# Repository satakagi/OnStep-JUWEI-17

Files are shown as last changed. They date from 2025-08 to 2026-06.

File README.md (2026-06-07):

# OnStep-JUWEI-17

## Table of Contents

- [Introduction](#introduction)  
- [Why This Project?](#why-this-project)  
- [Disclaimer](#disclaimer)  
- [Features](#features)  
- [Hardware](#hardware)  
- [Firmware and Config.h Configuration](#firmware-and-configh-configuration)  
- [Usage](#usage)
- [Optional Feature: GPS Integration](#optional-feature-gps-integration)
- [Licensing](#licensing)  
- [Contribution & Support](#contribution--support)  
- [Contact](#contact)

---

## Introduction

This repository contains the open-source hardware (OSH) design files (KiCad project) for a custom **OnStep-JUWEI-17** controller board specifically tailored for the JUWEI-17 harmonic drive equatorial mount. This board provides a robust and configurable solution for upgrading the JUWEI-17 mount with the powerful OnStep firmware, enhancing its tracking accuracy and GoTo capabilities.

The circuit design is based on Roman Hujer's OnStep ESP32 Mini project, with specific adaptations for the JUWEI-17 mount — most notably, a hardware-controlled brake system.

---

## Why This Project?

This project addresses a critical issue for users in Japan (and possibly elsewhere):  
The stock JUWEI-17 controller often includes a Wi-Fi/Bluetooth module that lacks Japan's Radio Law certification ([技適マーク - Giteki Mark](https://www.tele.soumu.go.jp/e/adm/monitoring/illegal/monitoring_qa/index.htm)). Operating such a device is illegal in Japan.

This **OnStep-JUWEI-17** project offers a compliant alternative, using certified ESP32 and ESP8266 (ESP-12F) modules that include Giteki certification.  
The goal is to provide a legal, open, and high-performance upgrade path for the JUWEI-17 mount.

---

## Disclaimer

This project involves electronic assembly, including SMD components. Risks include, but are not limited to, electric shock, fire, damage, or injury.

**This project is provided "as is", with no warranty.**  
Use at your own risk. While the board relies mostly on through-hole parts, experience with hand-soldering wide-pitch SMD components is strongly recommended.

---

## Features

- Based on Roman Hujer's [OnStep ESP32 Mini](https://oshwlab.com/hujer.roman/onstep-esp-mini), functionally similar to OnStep MAX ESP3  
- Drop-in installation into the JUWEI-17 mount — no enclosure modifications required  
- Hardware-Controlled Brake System: Uses the ENABLE signal from motor drivers — no firmware tweaks needed  
- Open-Source Hardware: KiCad design files included

---

## Hardware

Custom PCB tailored for the JUWEI-17, based on the OnStep ESP32 Mini reference.  
Operates on 12V DC, supporting the original brake solenoid and motor drivers.

Refer to the [ASSEMBLY_GUIDE.md](ASSEMBLY_GUIDE.md) for detailed component list and assembly instructions.

### Manufacturing Files
The complete set of Gerber and drill files required for PCB manufacturing can be found in the [KiCad/gerber/](KiCad/gerber/) directory. These files are ready for submission to a PCB fabrication service.

Location: [KiCad/gerber/](KiCad/gerber/)

---

## **Images**

Here are some visual references for the project.

### **Assembled Board**
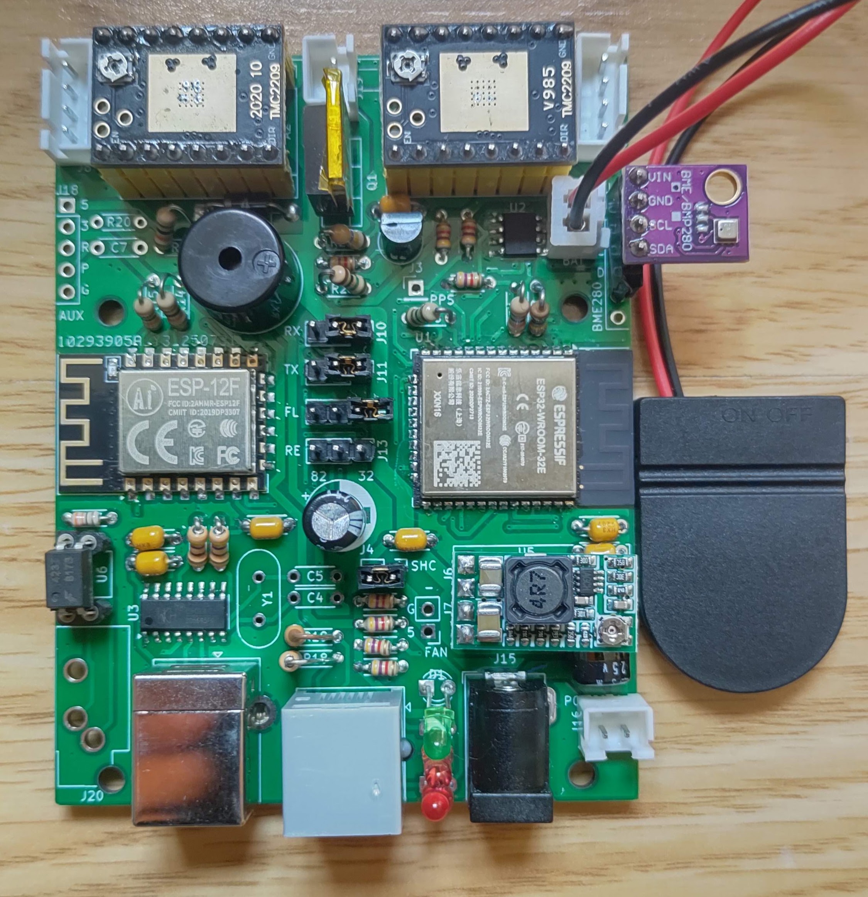
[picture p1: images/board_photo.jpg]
Assembled Board


### **Installed on JUWEI-17 Mount**
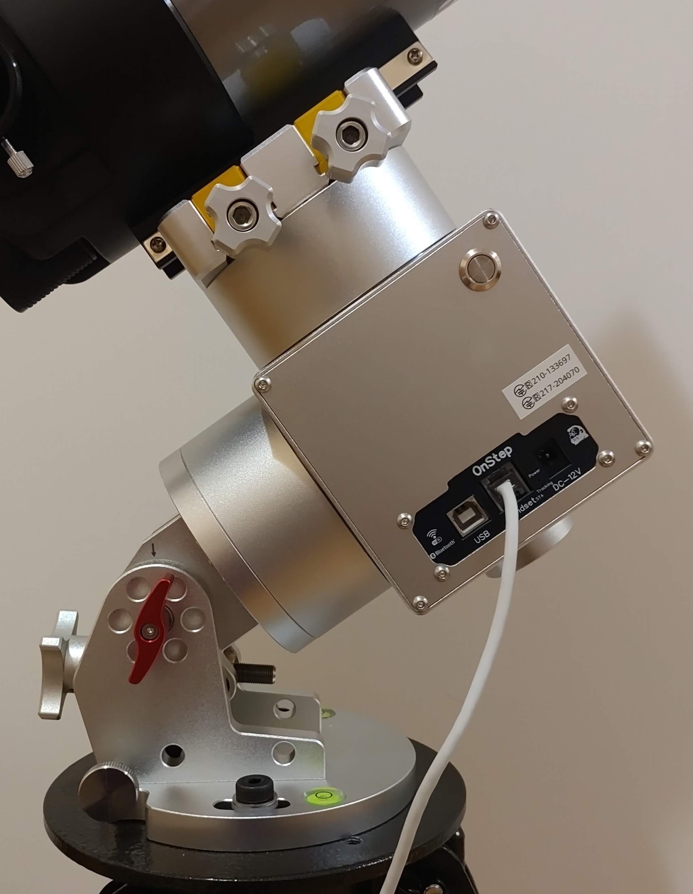
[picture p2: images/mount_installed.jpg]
Installed on JUWEI-17 Mount


### **PCB Design (Gerber View)**
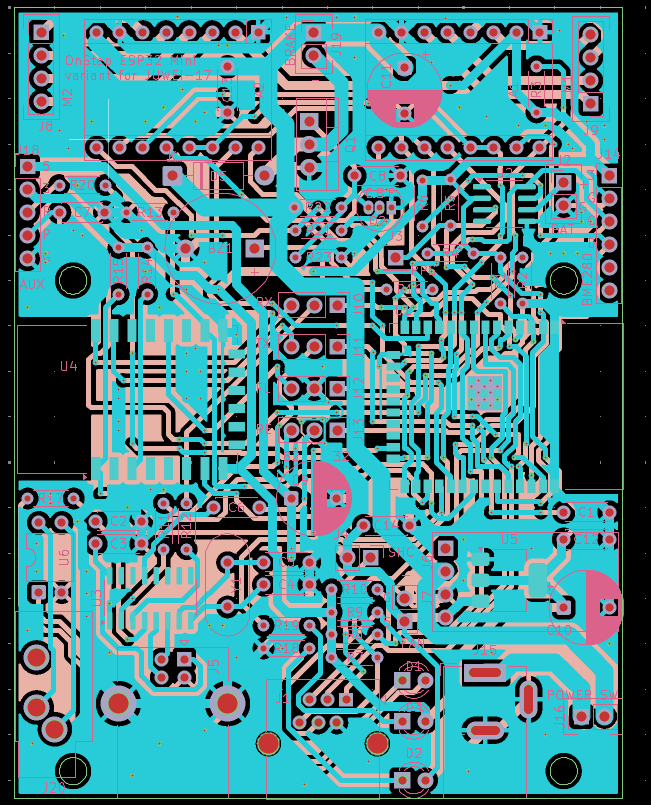
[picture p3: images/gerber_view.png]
PCB Design (Gerber View)


### **Schematic**
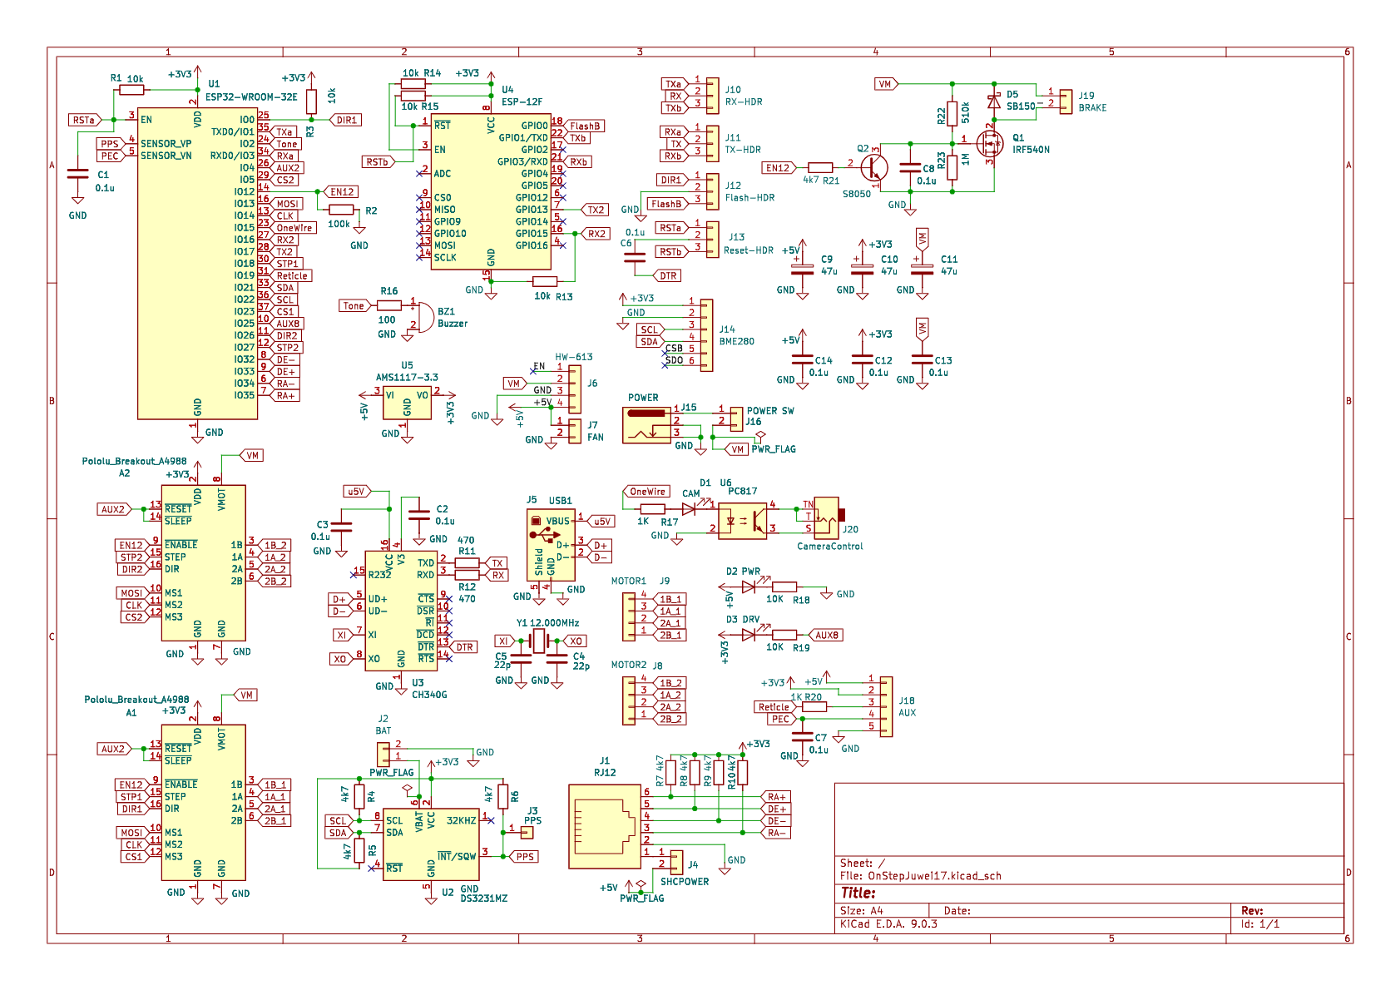
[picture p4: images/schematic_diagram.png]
Schematic


### **PCB image**
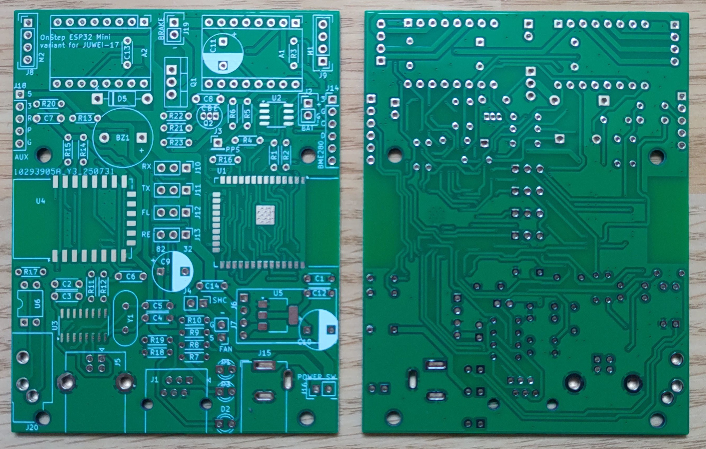
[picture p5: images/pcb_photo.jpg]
PCB image


---

## Firmware and Config.h Configuration

Uses standard OnStep firmware.  
Circuitry is nearly identical to the OnStep ESP32 Mini (minus the brake circuit), so you should reference that project for pin definitions and configurations.

---

### Specific Pin Map Settings

The pin map settings for this board are a modification of the standard Pins.MaxESP3.h file. They mirror the specific assignments documented by the [OnStep ESP32 Mini](https://oshwlab.com/hujer.roman/onstep-esp-mini) project on OSHWLab.

For your reference, the following assignments are replicated on this board:

- Aux7 = 36  
- OneWirePin = 15  
- ReticlePin = 19  
- TonePin = 2  
- PecPin = 39  
- AnalogPecPin = A3  

---

### ⚠️ Note for OnStepX Users

Variable names may differ in newer firmware.  
You will need to adapt these pin definitions to the appropriate structure in your version of Config.h and the corresponding Pins.*.h files.

---

### Gear Ratio Configuration

In Config.h, the gear ratio and motor settings must be exact. Errors will affect tracking and GoTo precision.

#### ⚠️ Important for JUWEI-17: "400:1" May Be Inaccurate

The JUWEI-17 mount is typically advertised with a gear system consisting of a 1:100 harmonic drive and a 1:4 pulley, for a total reduction of 400:1. The motors are standard NEMA17, with a 1.8°/step resolution.

However, based on user-reported data, the actual gear ratio appears to be 404:1, not 400:1.

From [Cloudy Nights post](https://www.cloudynights.com/topic/918425-juwei-17-mounts-on-aliexpress/?p=13665973):

- JUWEI original firmware uses 3591.111 steps/degree  
- Formula: (200 steps/rev × 16 microsteps × **101** x 4) ÷ 360 = 3591.111...

Harmonic drives can have ±1 variation depending on which spline is fixed.  
**Measure your actual gear ratio to ensure accuracy — do not trust online listings.**

---
<!-- TBD
### Sample Config Files

Sample Config.h and Pins.MaxESP3.h files are included in:

`Firmware_Examples/OnStepX_JUWEI-17/`

You must still modify them based on your stepper motors, gearing, and microstepping.

---
-->

### Important Notes on Configuration

- Ensure all pin/motor settings in Config.h and Pins.*.h match your board  
- Always re-upload firmware after making changes

---

## Tested and Confirmed Motor Driver Modules
The following motor driver modules have been successfully tested and confirmed to work with this board. The values in quotes ("...") are the corresponding AXIS?_DRIVER_MODEL settings in Config.h.

- BigTreeTech TMC2130 V3.0: "TMC2130"
- DRV8825 (Brand Unknown): "DRV8825"
- TMC2209 Module included with JUWEI-17 (Legacy Tested): "TMC2209S"

Note: All drivers were tested with 16 microsteps, which is the same setting as the original mount.

---

## Usage

To build and install this controller, follow the detailed instructions in [ASSEMBLY_GUIDE.md](ASSEMBLY_GUIDE.md).

---

## Optional Feature: GPS Integration
[A user successfully implemented](https://www.facebook.com/groups/349395118118532/posts/675489348842439/?comment_id=720520087672698) full GPS functionality by creatively repurposing existing pins on the AUX header and defining a Software Serial interface in OnStepX.

### Hardware and Wiring
- This method utilizes pins otherwise designated for PEC and the Reticle light:
- PPS Signal (Time Sync): Connect the GPS PPS (Pulse Per Second) output to the PEC Input (IO39).
- RX Data (Serial Data): Connect the GPS TX output (data) to the Reticle Pin (IO19).
- Critical Note: To ensure a clean signal path for the GPS, you must omit R20 and remove C7 during board assembly.

### Firmware Configuration
The GPS functionality must be enabled by defining the appropriate Software Serial pins within the OnStepX configuration file (Config.h).

---

## Licensing

This design is derived from the [OnStep ESP32 Mini](https://oshwlab.com/hujer.roman/onstep-esp-mini) project and is licensed under GPLv3.

✳️ _Note:_ Although GPLv3 is suitable for firmware, open hardware often benefits from dedicated licenses like the TAPR Open Hardware License (OHL). These better address physical product concerns such as patents and manufacturing rights.

---

## Contribution & Support

Contributions welcome!  
You can:

- Report bugs via GitHub Issues  
- Submit Pull Requests  
- Join discussion on Cloudy Nights forum

---

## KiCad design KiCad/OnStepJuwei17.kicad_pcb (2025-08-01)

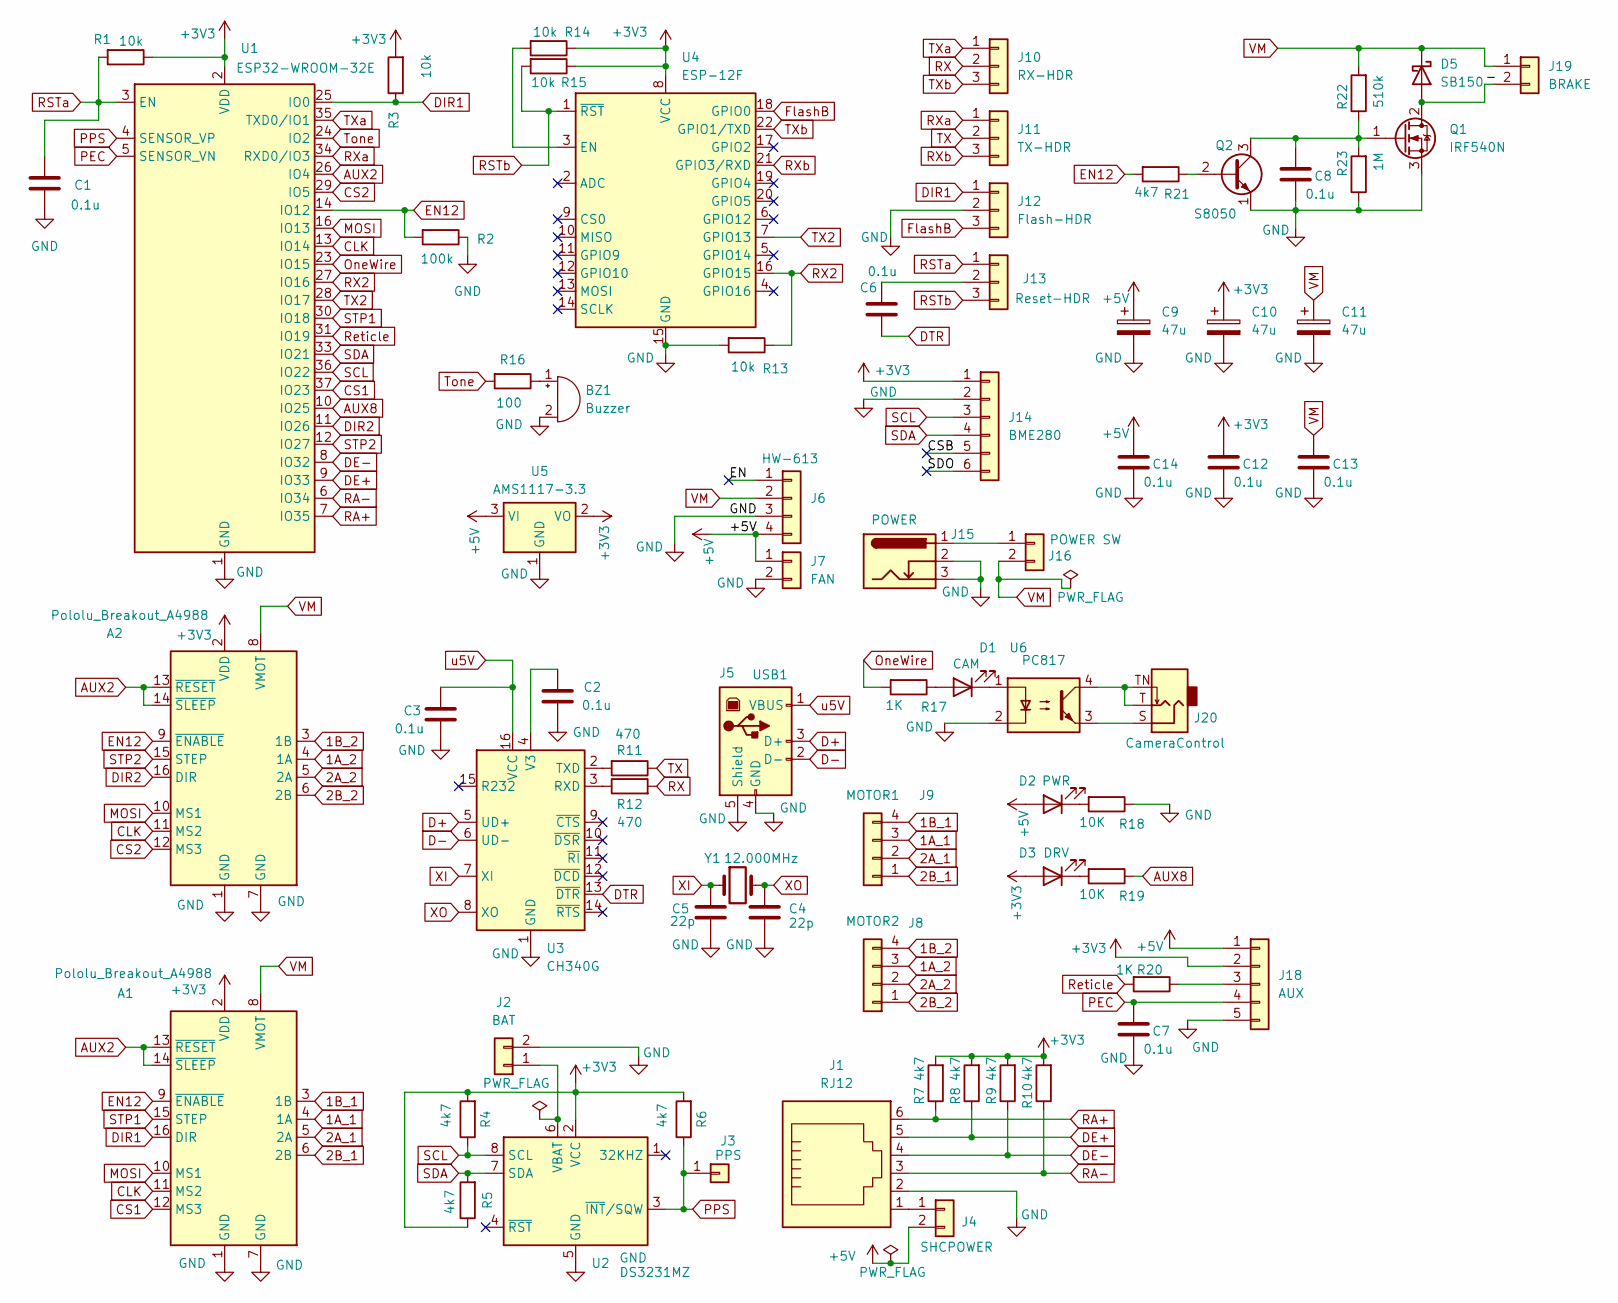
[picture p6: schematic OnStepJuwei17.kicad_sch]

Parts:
A1, A2: Pololu_Breakout_A4988; Pololu_Breakout-16_15.2x20.3mm
BZ1: Buzzer; Buzzer_12x9.5RM7.6
C1, C2, C3, C6, C7, C8, C12, C13, C14: 0.1u; C_Disc_D4.3mm_W1.9mm_P5.00mm
C4, C5: 22p; C_Disc_D4.3mm_W1.9mm_P5.00mm
C9, C10, C11: 47u; CP_Radial_D8.0mm_P5.00mm
D1: CAM; LED_D3.0mm
D2: PWR; LED_D3.0mm
D3: DRV; LED_D3.0mm
D5: SB150; D_DO-41_SOD81_P10.16mm_Horizontal
J1: RJ12; RJ25_Wayconn_MJEA-660X1_Horizontal
J2: BAT; PinHeader_1x02_P2.54mm_Vertical
J3: PPS; PinHeader_1x01_P2.54mm_Vertical
J4: SHCPOWER; PinHeader_1x02_P2.54mm_Vertical
J5: USB1; USB_B_Lumberg_2411_02_Horizontal
J6: HW-613
J7: FAN; PinHeader_1x02_P2.54mm_Vertical
J8: MOTOR2; PinHeader_1x04_P2.54mm_Vertical
J9: MOTOR1; PinHeader_1x04_P2.54mm_Vertical
J10: RX-HDR; PinHeader_1x03_P2.54mm_Vertical
J11: TX-HDR; PinHeader_1x03_P2.54mm_Vertical
J12: Flash-HDR; PinHeader_1x03_P2.54mm_Vertical
J13: Reset-HDR; PinHeader_1x03_P2.54mm_Vertical
J14: BME280; PinHeader_1x06_P2.54mm_Vertical
J15: POWER; BarrelJack_GCT_DCJ200-10-A_Horizontal
J16: POWER SW; PinHeader_1x02_P2.54mm_Vertical
J18: AUX; PinHeader_1x05_P2.54mm_Vertical
J19: BRAKE; PinHeader_1x02_P2.54mm_Vertical
J20: CameraControl; Jack_3.5mm_CUI_SJ1-3533NG_Horizontal_CircularHoles
Q1: IRF540N; TO-220-3_Vertical
Q2: S8050; TO-92_Inline
R1, R3, R13, R14, R15: 10k; R_Axial_DIN0204_L3.6mm_D1.6mm_P5.08mm_Horizontal
R2: 100k; R_Axial_DIN0204_L3.6mm_D1.6mm_P5.08mm_Horizontal
R4, R5, R6, R7, R8, R9, R10, R21: 4k7; R_Axial_DIN0204_L3.6mm_D1.6mm_P5.08mm_Horizontal
R11, R12: 470; R_Axial_DIN0204_L3.6mm_D1.6mm_P5.08mm_Horizontal
R16: 100; R_Axial_DIN0204_L3.6mm_D1.6mm_P5.08mm_Horizontal
R17, R20: 1K; R_Axial_DIN0204_L3.6mm_D1.6mm_P5.08mm_Horizontal
R18, R19: 10K; R_Axial_DIN0204_L3.6mm_D1.6mm_P5.08mm_Horizontal
R22: 510k; R_Axial_DIN0204_L3.6mm_D1.6mm_P5.08mm_Horizontal
R23: 1M; R_Axial_DIN0204_L3.6mm_D1.6mm_P5.08mm_Horizontal
U1: ESP32-WROOM-32E; ESP32-WROOM-32D
U2: DS3231MZ; SOIC-8_3.9x4.9mm_P1.27mm
U3: CH340G; SOIC-16_3.9x9.9mm_P1.27mm
U4: ESP-12F; ESP-12E
U5: AMS1117-3.3; SOT-223-3_TabPin2
U6: PC817; DIP-4_W7.62mm
Y1: 12.000MHz; Crystal_HC49-4H_Vertical

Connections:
1A_1: A1.4 (1A), J9.3
1A_2: A2.4 (1A), J8.3
1B_1: A1.3 (1B), J9.4
1B_2: A2.3 (1B), J8.4
2A_1: A1.5 (2A), J9.2
2A_2: A2.5 (2A), J8.2
2B_1: A1.6 (2B), J9.1
2B_2: A2.6 (2B), J8.1
+3V3: A1.2 (VDD), A2.2 (VDD), C10.1, C12.1, D3.2 (A), J14.1, J18.2, R1.1, R3.2, R4.2, R5.1, R6.2, R7.2, R8.2, R9.2, R10.2, R14.1, R15.1, U1.2 (VDD), U2.2 (VCC), U4.8 (VCC), U5.2 (VO)
+5V: C9.1, C14.1, D2.2 (A), J4.2, J6.4, J7.1, J18.1, U5.3 (VI)
/-: D5.2 (A), J19.2, Q1.2 (D)
/CSB: J14.5
/EN: J6.1
/SDO: J14.6
AUX2: A1.13 (~RESET), A1.14 (~SLEEP), A2.13 (~RESET), A2.14 (~SLEEP), U1.26 (IO4)
AUX8: R19.1, U1.10 (IO25)
CLK: A1.11 (MS2), A2.11 (MS2), U1.13 (IO14)
CS1: A1.12 (MS3), U1.37 (IO23)
CS2: A2.12 (MS3), U1.29 (IO5)
D+: J5.3 (D+), U3.5 (UD+)
D-: J5.2 (D-), U3.6 (UD-)
DE+: J1.5, R8.1, U1.9 (IO33)
DE-: J1.4, R9.1, U1.8 (IO32)
DIR1: A1.16 (DIR), J12.1, R3.1, U1.25 (IO0)
DIR2: A2.16 (DIR), U1.11 (IO26)
DTR: C6.1, U3.13 (~DTR)
EN12: A1.9 (~ENABLE), A2.9 (~ENABLE), R2.2, R21.2, U1.14 (IO12)
FlashB: J12.3, U4.18 (GPIO0)
GND: A1.1 (GND), A1.7 (GND), A2.1 (GND), A2.7 (GND), BZ1.2 (-), C1.2, C2.2, C3.2, C4.2, C5.2, C7.2, C8.2, C9.2, C10.2, C11.2, C12.2, C13.2, C14.2, J1.2, J2.2, J5.4 (GND), J5.5 (Shield), J6.3, J7.2, J12.2, J14.2, J15.2, J15.3, J18.5, Q1.3 (S), Q2.1 (E), R2.1, R13.2, R18.1, R23.1, U1.1 (GND), U1.15 (GND), U1.38 (GND), U1.39 (GND), U2.5 (GND), U3.1 (GND), U4.15 (GND), U5.1 (GND), U6.2
MOSI: A1.10 (MS1), A2.10 (MS1), U1.16 (IO13)
unnamed: BZ1.1 (+), R16.1
unnamed: D1.2 (A), R17.1
unnamed: D1.1 (K), U6.1
unnamed: D2.1 (K), R18.2
unnamed: D3.1 (K), R19.2
unnamed: J2.1, U2.6 (VBAT)
unnamed: J1.1, J4.1
unnamed: C6.2, J13.2
unnamed: J15.1, J16.1
unnamed: J18.3, R20.1
unnamed: J20.S, U6.3
unnamed: J20.T, J20.TN, U6.4
unnamed: C8.1, Q1.1 (G), Q2.3 (C), R22.1, R23.2
unnamed: Q2.2 (B), R21.1
unnamed: R12.1, U3.3 (RXD)
unnamed: R11.2, U3.2 (TXD)
unnamed: C2.1, U3.4 (V3)
unnamed: R14.2, U4.3 (EN)
OneWire: R17.2, U1.23 (IO15)
PEC: C7.1, J18.4, U1.5 (SENSOR_VN)
PPS: J3.1, R6.1, U1.4 (SENSOR_VP), U2.3 (~INT/SQW)
RA+: J1.6, R7.1, U1.7 (IO35)
RA-: J1.3, R10.1, U1.6 (IO34)
RSTa: C1.1, J13.1, R1.2, U1.3 (EN)
RSTb: J13.3, R15.2, U4.1 (~RST)
RX: J10.2, R12.2
RX2: R13.1, U1.27 (IO16), U4.16 (GPIO15)
RXa: J11.1, U1.34 (RXD0/IO3)
RXb: J11.3, U4.21 (GPIO3/RXD)
Reticle: R20.2, U1.31 (IO19)
SCL: J14.3, R4.1, U1.36 (IO22), U2.8 (SCL)
SDA: J14.4, R5.2, U1.33 (IO21), U2.7 (SDA)
STP1: A1.15 (STEP), U1.30 (IO18)
STP2: A2.15 (STEP), U1.12 (IO27)
TX: J11.2, R11.1
TX2: U1.28 (IO17), U4.7 (GPIO13)
TXa: J10.1, U1.35 (TXD0/IO1)
TXb: J10.3, U4.22 (GPIO1/TXD)
Tone: R16.2, U1.24 (IO2)
VM: A1.8 (VMOT), A2.8 (VMOT), C11.1, C13.1, D5.1 (K), J6.2, J16.2, J19.1, R22.2
XI: C5.1, U3.7 (XI), Y1.1
XO: C4.1, U3.8 (XO), Y1.2
u5V: C3.1, J5.1 (VBUS), U3.16 (VCC)

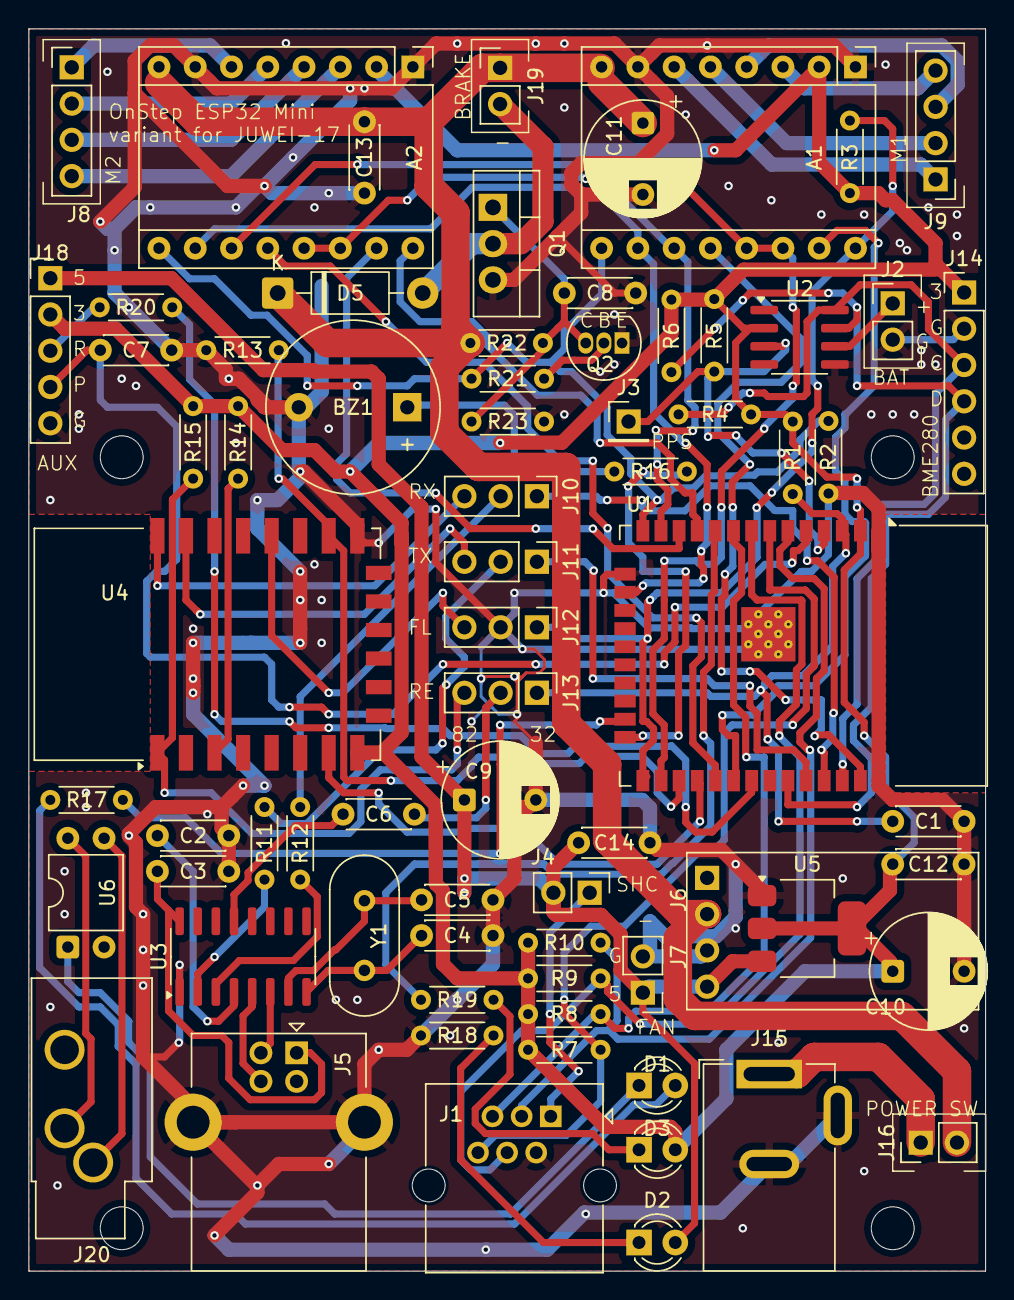
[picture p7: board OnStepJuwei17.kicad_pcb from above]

Board: 2 copper layers, 67.0 x 87.0 mm, 72 parts (0 on the bottom side), 70 nets.

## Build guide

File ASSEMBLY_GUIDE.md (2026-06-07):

# **Assembly Guide for JUWEI-17 Mount OnStep Open-Source Controller Board**

This document provides detailed instructions and critical considerations for assembling the OnStep controller board for the JUWEI-17 EQ mount. Meticulous attention to component selection and placement is essential for the proper functioning of the board.

## **1\. Introduction**

Before beginning the assembly of this PCB, it is assumed that you have experience with soldering and basic electronics. If you are unsure about any steps, it is recommended to consult with experienced individuals or refer to relevant resources.

As a design concept, this board prioritizes through-hole components to facilitate manual assembly. It does contain a few SMD parts (like the CH340), but their pitches are relatively wide and should pose no problem for those who have experience with hand-soldering surface-mount devices.

## **2\. Special Assembly Notes**

The design of this PCB includes important considerations for component selection and placement. Following these instructions will help prevent assembly errors and component damage.

### **2.1 Certified Wi-Fi/Bluetooth Modules**
This board is designed to be used with Giteki-certified ESP32 or ESP8266 modules for legal operation in Japan. When sourcing modules, please ensure they have the official Giteki mark.

Recommended Modules (with Giteki Mark):

* ESP32: Espressif's ESP32-WROOM-32, ESP32-WROOM-32D, and ESP32-WROOM-32E
* ESP8266: Ai-Thinker Technology's ESP-12F

### **2.2. DCDC Converter (e.g., HW-613) Installation Notes**

The HW-613 DCDC converter module features a jumper (or solder pad) to set its output to a fixed 5V. However, there is a **critical, easily overlooked detail that can lead to significant frustration** (a pitfall I personally encountered during assembly\!): simply closing this jumper is often not enough to fix the output at 5V.

By default, the module is configured for variable voltage output via a potentiometer. To correctly fix the output at 5V, you **must first sever a very fine jumper trace** on the module itself. This trace is often **extremely thin and can appear almost invisible or disguised by the solder mask**, making it easy to miss. It might look like there's no connection there at first glance, but a close inspection will reveal it right next to the pads intended for the ADJ jumper.

**Action Required:** Carefully locate this hidden, fine trace (refer to the image below) and **cut it completely with a sharp hobby knife or scalpel.** Ensure the trace is fully severed.

**Why it's critical:** If this hidden jumper trace is not cut, the module will **fail to fix its output to 5V**, even if you properly close the designated 5V fixed-output jumper. Instead, it will typically output an incorrect, oddly fixed voltage (e.g., around 3.8V), which will prevent the board from operating as expected.

Only after ensuring this hidden trace is completely cut should you proceed to close the designated jumper or solder bridge to set the module's output to a fixed and stable 5V.

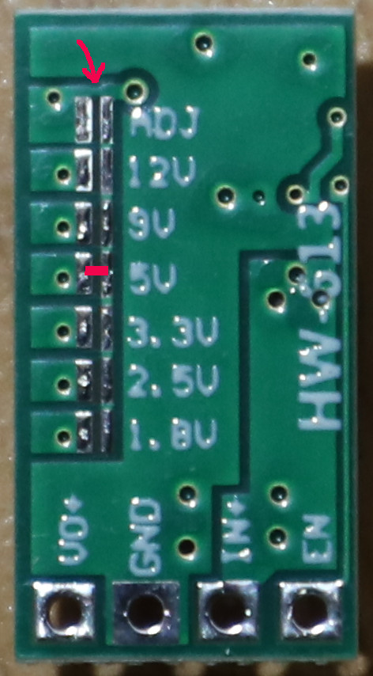
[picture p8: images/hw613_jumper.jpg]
close-up photo of the HW-613 module, with the specific, hidden jumper trace


### **2.3. Brake Control Circuit Component Selection and Other Considerations**

The PCB footprints for the transistors in this circuit are designed for **through-hole (TH) packages**. While component substitutions *might* be possible, **extreme caution is advised**. When using substitutes, **you *must* verify the datasheet for its pinout, voltage/current ratings, and power dissipation.** Using an incorrect or unsuitable substitute component can lead to malfunction or damage to the board.

a. Bipolar Transistor (NPN \- e.g., S8050 \- TO-92 Package)  
The design is optimized for an S8050 (TO-92). Common general-purpose NPN transistors like 2N3904, BC547, or 2SC1815 may be used as substitutes if their ratings are sufficient for the brake's current requirements and their gain is adequate for the base drive.

* **Critical Pinout Note:** Be acutely aware that **pinouts can differ significantly even for similar transistors in the same TO-92 package\!** For example, while the S8050 (TO-92) often has an Emitter-Base-Collector (EBC) pinout, a very common transistor like the 2SC1815 (also TO-92) typically has an Emitter-Collector-Base (ECB) pinout. The PCB design released in this repository has been updated to accommodate the S8050's EBC pinout. **Inserting a transistor with the wrong pinout will almost certainly damage the component or prevent the circuit from functioning. Always double-check the datasheet for your specific substitute part.**

b. Power MOSFET (N-Channel \- e.g., LR7843, IRF540/IRF520/2SK4017)  
The design is compatible with TO-220 through-hole package N-channel power MOSFETs (or adaptable TO-251 like 2SK4017). Examples include the LR7843 (original in schematic), IRF540 (listed option), or IRF520 (my personal choice). The 2SK4017 (often in TO-251 package) is also a suitable alternative.  
Common solenoid brakes for NEMA17 stepper motors, operating at 12V, typically consume less than 5W. This means they draw approximately 0.42 Amperes (420mA) of continuous current.  
Given this common low current requirement:

* All listed MOSFETs are **more than capable** of handling this continuous current load.  
* Heat dissipation will be **negligible**, so a heatsink is **not required**.  
* The **LR7843** is a "logic-level" MOSFET with very low on-resistance (Rds(on)), making it highly efficient even with 3.3V logic drive. The IRF520/IRF540 and 2SK4017 also function reliably for this low current, though the IRF series generally prefer higher gate voltages for optimal performance.  
* **Critical Pinout Note:** While many TO-220/TO-251 N-channel power MOSFETs share a common Gate-Drain-Source (GDS) pinout, **always verify the datasheet for your specific substitute part to confirm its pinout** and specifications.

c. Solenoid Protection Diode and Capacitor  
The circuit includes a diode for flyback protection across the solenoid. While the original part number is unknown, any general-purpose Schottky or fast-recovery diode should be suitable. Select a diode with sufficient current and voltage ratings for your solenoid.  
A capacitor (e.g., 0.1uF in my build) is placed in the brake solenoid control circuit for noise suppression. While its exact value is not extremely critical for basic operation, 0.1uF is a common choice for general noise filtering.  

d. Hardware-Controlled Brake System Addendum  
This JUWEI-17 specific board features a fully hardware-controlled brake system. The brake is automatically engaged or disengaged by detecting the ENABLE signal from the motor drivers, meaning no OnStep software modifications, patches, or specific Config.h brake pin configurations are required for this board's brake functionality.

### **2.4. Other Important Assembly Considerations**

a. PCB Mounting & Spacers:  
Some signal traces are very close (approx. 1mm) to the PCB mounting holes. Therefore, using insulating hardware like nylon nuts and spacers is highly recommended to prevent potential shorts, even though the PCB has solder mask and the enclosure might be anodized. (Refer to provided photos for my mounting method).  

b. Connector Orientation & Polarity:  
Pay close attention to connector polarity for all connectors (especially power, motors, and sensors).

* The **brake solenoid connector** is polarity-sensitive.  
* The **RTC backup coin cell holder** also requires correct orientation.  
* While silkscreen markings provide guidance, always double-check with a multimeter if unsure.  
* Motor connector polarity is generally less critical, as motor direction can often be adjusted in the OnStep config.h file.

c. USB Serial IC (CH340):  
The PCB pattern for the USB-to-Serial converter is designed for the CH340G, which typically requires an external crystal and its load capacitors. However, I successfully used a CH340C, which does not require these external components. (My assembly photos reflect this, showing an absent crystal and its capacitors).  

d. LED Current-Limiting Resistors:  
The resistor values for the LEDs were transcribed directly from the original author's schematic. I have set them to allow approximately 7mA of current to flow to each LED.

**Note on Recommended Values:** While the schematic provides initial values, for optimal brightness (assuming red LEDs with ~1.9V forward voltage) and safe operation, the following resistor values are recommended:

* **D2 PWR (Power Indicator):** Change R18 to **470Ω** (from 10KΩ) for ~6.6mA current from 5V.
* **D3 DRV (Drive Indicator):** Change R19 to **220Ω** (from 10KΩ) for ~6.4mA current from 3.3V.

e. Camera Shot Circuit:  
The camera shot control circuit has been tested and confirmed to work with this board. 

**Note on Recommended Values:** The schematic specifies R17 as 1KΩ. However, through personal testing, a **green indicator LED was found to work reliably with a 33Ω resistor**, producing a reasonable brightness. This suggests the specific green LED used has a lower forward voltage than typical datasheet values. A red indicator LED in series with the PC817's internal LED (total forward voltage ~3.1V) would also work, but for more reliable operation with a standard green LED, it is recommended to test with a resistor value in the range of **33Ω to 47Ω**.

f. External Battery Backup (RTC):  
The battery backup for the RTC is external. A standard coin cell (such as CR2032) holder should be connected to the designated connector on the board.  

g. Buzzer (TonePin):  
The board includes a footprint for a buzzer connected to the TonePin. OnStep firmware supports both passive (piezo speaker type) and active buzzers, with selection often configurable in Config.h. For this board, I have successfully tested with a passive piezo type buzzer.

### **2.5. Jumper Settings**

Several jumpers on the PCB control important functionalities. It is crucial to set these correctly for your desired operation. **For the definitive location and function of each jumper, always refer to the KiCad schematic files provided in the repository.**

* **J4 (SHC \- Smart Hand Controller Power):** This jumper is used to **supply power to the Smart Hand Controller (SHC)** if you intend to use one with this board. Ensure it is connected if an SHC is utilized.  
* **J10-J13 (Firmware Upload & USB Selection Jumpers):** These jumpers are critical for both firmware uploading and selecting which processor receives USB communication.  
  * **J10 & J11 (USB RX/TX Selection):** These jumpers select which processor (ESP32 \- main OnStep computer, or ESP8266 \- Smart Web Server) the USB RX and TX lines are connected to.  
    * For **firmware upload**, connect J10 and J11 to the respective processor (ESP32 or ESP8266) you wish to program via USB.  
    * For **normal operation**, J10 and J11 should be connected to the **ESP32 (main processor) side** to allow communication with the primary OnStep controller.  
  * **J12 (Firmware Upload Enable):** This jumper is used to put the selected processor into **bootloader mode** for firmware uploading. It must be set appropriately when flashing firmware to either the ESP32 or ESP8266.  
  * **J13 (DTR Reset):** This jumper is used in conjunction with the DTR (Data Terminal Ready) signal from the USB-to-Serial converter to perform a **reset** on the selected processor, which is often required for initiating firmware uploads.

**Always consult the KiCad schematic for the exact configuration required to enable firmware upload and select the correct processor for USB communication.**

### **2.6. Connector Selection & Sourcing**

To ensure proper fit and function, please pay close attention to the following connector specifications.

* **JST XH Connectors**: The connectors that appear **white** on the PCB photo (two 4-pin and three 2-pin) are **JST XH type**. These are standard and widely available.

* **6P6C (RJ12) Connector**: The connector for the RJ12 port is a **horizontal type (through-hole)**. **Crucially, the pins (electrodes) must be located on the *bottom* side of the connector.** Some similar-looking connectors have the pins on the top side, which are not compatible with this PCB layout. Double-check this detail before purchasing.

* **Component Sourcing Note**: For resistors and XH connectors, it is often more economical and convenient to purchase an **assortment kit**. These kits typically contain a wide range of values or pin counts, which can be very helpful for prototyping and avoiding the need to order individual components separately.
